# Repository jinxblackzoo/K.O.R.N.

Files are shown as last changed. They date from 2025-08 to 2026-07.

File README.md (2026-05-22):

# K.O.R.N.
**Katastrophal Organisierter Runder Nahrungsmittelspender**

K.O.R.N. ist ein robuster, Open-Source/Hardware, wasserdichter, mit einfachen Mitteln konstruierter und mäusesicherer Fütterungsautomat für Geflügel.

## Lizenz
Attribution-NonCommercial-ShareAlike 4.0 International

## 🎯 Projektübersicht

Aufgrund der enttäuschenden Erfahrung mit gekauften Fütterungsautomaten welche trotz der teils hohen Preise entweder nach drei Wochen defekt waren, oder ganze Mäusefamilien durchfütterten, musste eine Eigenkonstruktion her. Die Entscheidungsgrundlage für das gewählte System mit einer Förderschnecke in einem Rohr, basiert auf einer Recherche im Dubbel Ausgabe von 2001.

Es handelt sich um einen **Stetigförderer (Schnecke)**, der Schüttgut (Futter) aus einem Silo (KG-Rohr) in einen Auswurfschacht befördert. Das Gehäuse besteht aus überall erhältlichen, robusten und günstigen HT-, bzw KG-Rohren.

## Revision 1 wurde verworfen

## Revision 2 enthält die neuen CAD-Dateien und eine Steuerung mit ARDUINO Uno R3

Revision 2 wurde entwickelt als supersimple, autarke und stromsparende Version ohne Extra-Features.

## Revision 3 basiert auf den CAD Dateien von Rev.2 und einer Steuerung mit ARDUINO Uno R4 WiFi ✅ Fertig

Revision 3 wurde entwickelt als autarke Off-Grid Funktion. Ein WLAN mit Internetverbindung ist hier nicht vorgesehen.
Stattdessen kann KORN mitten im Feld ohne eigene Internetverbindung installiert werden. Der Arduino UNO R4 spannt einen eigenen WLAN Accesspoint auf. Mit diesem kann man sich mittels Smartphone verbinden.
Tipp: Alte Smartphones ohne Internet/Benutzerdaten einfach auf Werkseinstellungen zurücksetzen. Dann mit dem WLAN "KORN" verbinden und im Browser `192.168.4.1` öffnen. Voilà, fertig ist das eigene CCCC (ChickenCoopControlCenter) 🥳 😉

## Revision 3.5 basiert auf Rev.3 (Arduino UNO R4 WiFi) mit neuer WLAN-Logik ✅ Fertig

Revision 3.5 verwendet die gleiche Hardware und CAD wie Rev.3/Rev.4, ändert jedoch den WLAN-Betrieb grundlegend:
Statt eines eigenen Access Points verbindet sich KORN nun mit einem vorhandenen Heimnetz (WLAN-Router).

**Neue Features:**
- **DHCP-Hostname "KORN"**: Im Router als Gerät "KORN" sichtbar, direkt erreichbar unter `http://korn` (FritzBox, Speedport, OpenWRT)
- **Captive Portal**: Automatische Browser-Öffnung bei Einrichtungs-AP (`KORN-Setup`, PW: `Chaosfeeder`)
- **NTP-Zeitsteuerung**: Internetzeit statt DS1302 RTC (mit Sommer-/Winterzeit)
- **Buzzer-Jagdsignal**: Akustisches Signal "Zum Essen" (3/8-Takt) während der Fütterung
- **WPA2-Unterstützung** mit Passwort-Validierung (8-63 Zeichen)
- **Optionales Admin-Passwort**: Web-UI-Schutz vor unautorisierten Zugriffen im Heimnetz
- **Hardware-Recovery**: Bei vergessenem Passwort – Knopf (Pin 10↔11) zur Laufzeit 10s halten → EEPROM-Reset (Buzzer warnt ab 5s, Abbruch durch Loslassen möglich)

**24/7-Betriebssicherheit:**
- **Hardware-Watchdog (4s)**: Automatischer Reboot bei Code-Hängern
- **Stromausfall-Schutz**: EEPROM persistiert letzte Fütterung → keine Doppel-Fütterung nach Reboot
- **Robuster WLAN-Reconnect**: Bei vorhandenen Credentials kein automatischer Setup-AP-Modus
- **HTTP-Timeouts optimiert**: 500ms statt 1500ms → weniger Loop-Blockaden
- **XSS-Schutz**: HTML-Escaping & URL-Encoding für Admin-Passwort
- **NTP-Drift-Schutz**: Erkennt kleine Rückwärtssprünge bei NTP-Resync und verhindert dadurch ausgelöste Geister-Fütterungen (Mai 2026)

**Diagnose & Monitoring:**
- **Volles Datum + Uhrzeit** (`YYYY-MM-DD HH:MM:SS`) auf Web-UI und seriellem Monitor
- **Event-Log auf der Webseite** (`/log`): RAM-Ringpuffer mit den letzten 24 Scheduler-Ereignissen (Boot, NTP-Sync, Crossings, Trigger, Tageswechsel, Drift) – Fehlersuche ohne angeschlossenen Laptop

**Ablauf:** Beim ersten Start oder bei fehlendem WLAN öffnet der Arduino einen temporären Einrichtungs-AP. Nach Speichern der Zugangsdaten verbindet sich KORN automatisch mit dem Heimnetz.

📖 **Detaillierte Dokumentation:** [`KORN_Rev3.5/README_REV3.5.md`](./KORN_Rev3.5/README_REV3.5.md)

## Revision 4 basiert auf Rev.3/3.5 CAD mit neuem Controller: Raspberry Pi Pico W (Geplant)

Revision 4 übernimmt die überarbeiteten CAD-Dateien (Wendel 4.0, neuer Achsträger, Arduino-Träger als Pico-Träger).
Als Controller wird ein Raspberry Pi Pico W eingesetzt. Die Software wird in MicroPython neu geschrieben.
Ebenfalls geplant ist eine eigene Platine für eine sauberere Verkabelung und Befestigung.

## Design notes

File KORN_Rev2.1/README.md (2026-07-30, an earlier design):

# K.O.R.N.
**Katastrophal Organisierter Nahrungsmittel Spender**

K.O.R.N. wurde geplant als robuster, Open-Source/Hardware, wasserdichter, mit einfachen Mitteln konstruierter und mäusesicherer Fütterungsautomat für Geflügel.

Aufgrund der enttäuschenden Erfahrung mit gekauften Fütterungsautomaten, welche trotz teils hoher Preise entweder nach drei Wochen defekt waren oder ganze Mäusefamilien durchfütterten, musste eine Eigenkonstruktion her. Die Entscheidungsgrundlage für das gewählte System mit einer Förderschnecke in einem Rohr basiert auf einer Recherche im Dubbel, Ausgabe von 2001.

Es handelt sich um einen Stetigförderer (Schnecke), der Schüttgut (Futter) aus einem Silo (KG-Rohr) in einen Auswurfschacht befördert. Die Fütterungszeit und die Menge sind im Arduino-Code einstellbar. Das Gehäuse besteht aus überall erhältlichen, robusten und günstigen HT- bzw. KG-Rohren, die das Futter vor Mäusen, Insekten und Feuchtigkeit schützen sollen.

Die elektronischen Bauteile sind leicht verfügbar, standardisiert und günstig zu beschaffen. Alle Datenblätter und Schaltpläne sind online auffindbar.

Die Bauteile der Förderschnecke wurden mit FreeCAD (LGPL2+, CC-BY-3.0) entworfen. Die Förderschnecke wurde steckbar entworfen, sodass sie auch auf kleineren 3D-Druckern gedruckt werden kann.

## Funktionsweise Rev2

Der Arduino UNO R4 WiFi steuert über eine **DS3231 Echtzeituhr (RTC)** eine tägliche Fütterungszeit. Das Datum der letzten Fütterung wird im flash-emulierten EEPROM des R4 WiFi gespeichert und überlebt so Stromausfälle und Resets. Die Fütterung erfolgt innerhalb eines definierbaren Fensters um die Zielzeit herum; danach gibt es ein Nachholfenster. Anschließend schaltet ein Relais die Stromversorgung des Motortreibers ein, der NEMA-17-Stepper fördert das Futter für eine einstellbare Dauer und wird danach wieder stromlos geschaltet.

## Materialliste

**Gekauft:**
- 1x NEMA-17 Stepper Motor (z. B. 17HS15-1504S-X1)
- 1x Arduino UNO R4 WiFi
- 1x DM320T Motortreiber
- 1x Relais-Modul (z. B. HW-482)
- 1x DS3231 RTC-Modul
- Diverse KG-/HT-Rohre
- Diverse Kabel und 5-mm-Stecker für Arduino
- 12 V / 1,5 A Netzteil
- 4x Schrauben M3 für Stepper
- Kleber für PLA (z. B. Pattex Ultra Gel Sekundenkleber)

**Selbst gedruckt:**
- 3x 3D-Druck Förderschnecke/Wendel
- 1x 3D-Druck Achsträger
- 1x 3D-Druck Motorträger
- 1x 3D-Druck Zahnrad-Achse
- 1x 3D-Druck Achse-Achsträger

## Verdrahtung

**DS3231 RTC:**
- VCC → Arduino 3,3 V oder 5 V
- GND → Arduino GND
- SDA → Arduino A4 (SDA)
- SCL → Arduino A5 (SCL)
- SQW → nicht anschließen! (Pin 2 ist durch PUL belegt; bei Bedarf z. B. Pin 7 nutzen)

**Motortreiber:**
- PUL+ → Arduino Pin 2
- DIR+ → Arduino Pin 3
- ENA+ → Arduino Pin 5

**Relais:**
- Relais IN → Arduino Pin 8

**EEPROM-Reset:**
- Jumper/Kabel zwischen Pin 12 und Pin 13 → löscht das gespeicherte Fütterungsdatum
- Beim Start: sofort löschen
- Im laufenden Betrieb: Jumper mindestens 3 Sekunden halten
- Nach dem Löschen Jumper entfernen (ansonsten wird bei jedem Neustart gelöscht)

## Konfiguration im Code

Die wichtigsten Parameter in `main/KORN-Motorsteuerung_Rev2.1_R4WiFi/KORN-Motorsteuerung_Rev2.1_R4WiFi.ino`:

> **Hinweis:** Die hier gezeigten Werte sind **Beispielwerte**. Alle Parameter (Fütterungszeit, Fütterungsdauer/Menge, Timing) werden direkt im Code an die eigenen Gegebenheiten angepasst (z. B. Größe der Hühnerschar) und können von diesem Beispiel abweichen.

```cpp
// Fütterungszeit (24h-Format)
// ACHTUNG: Keine führende Null verwenden (z.B. 07, 09) - C++ wertet das als Oktalzahl!
const int FUETTERUNG_STUNDE_1 = 7;   // Fütterung: 07:01 Uhr
const int FUETTERUNG_MINUTE_1 = 1;

// Motorparameter
const int MOTOR_BESCHLEUNIGUNG = 2000; // Beschleunigung in Steps/s²
const int SCHRITTFREQUENZ = 1000;      // Steps pro Sekunde (fix)
const int FUETTERUNG_DAUER_SEK = 5;    // Fütterungsdauer in Sekunden (1–60 s)
const bool MOTOR_RECHTS = false;        // true = rechts (CW), false = links (CCW)

// Timing-Parameter
const int RELAIS_VERZOEGERUNG = 2000;  // ms zwischen Relais-Ein und Motor-Start
const int MOTOR_PAUSE = 5000;          // ms nach Motorlauf bevor Relais aus
const int LOOP_INTERVALL = 10;         // Sekunden zwischen zwei Loop-Durchläufen
const int ZEIT_AUSGABE_INTERVALL = 10; // Statusausgabe alle 10 Sekunden
const int FUETTERUNGS_FENSTER_MIN = 2; // Fütterungsfenster: Zielzeit bis +2 Minuten
const int NACHHOLFENSTER_MIN = 60;    // Nachholfenster: Zielzeit bis +60 Minuten

// Automatische Zeitsynchronisation
const bool ZEIT_EINSTELLEN = false;    // Nur true, wenn lostPower() oder explizit gewünscht
```

**Hinweis zur Zeit:** Die RTC-Zeit wird automatisch auf die Build-Zeit gesetzt, wenn die RTC ihre Versorgung verloren hat (`lostPower()`) oder `ZEIT_EINSTELLEN` auf `true` gesetzt wird. Nach dem ersten Flashen ist eine manuelle Synchronisation nur bei Bedarf nötig.

**Serieller Monitor:** 9600 Baud einstellen.

## Fehlerverhalten / Sicherheit

- **RTC nicht gefunden:** Wird die DS3231 beim Start nicht erkannt, wird alle 5 Sekunden ein neuer Verbindungsversuch unternommen. Sobald die RTC wieder erreichbar ist, startet das System normal weiter.
- **Ungültige RTC-Zeit:** Liefert die RTC unplausible Werte (z. B. durch eine I2C-Störung), wird der Durchlauf übersprungen. Das verhindert falsche Tagesresets und Doppelfütterungen.
- **Watchdog:** Aktuell deaktiviert, da er einen Reset-Loop verursacht hat. Soll später über einen Hardware-Timer sauber wieder integriert werden.

## Fütterungslogik in einfachen Worten

Der Arduino merkt sich im EEPROM das **Datum der letzten Fütterung** (Tag, Monat, Jahr). Das reicht, weil sich das Datum durch Stromausfälle und Resets nicht verliert.

### Ablauf

1. **Beim Start** liest er dieses Datum aus dem EEPROM.
2. **Alle 10 Sekunden** liest er die aktuelle Uhrzeit und prüft die Fütterungsfenster.
3. Er berechnet die **Zielzeit** aus den konfigurierten Stunden/Minuten:
   - **Fütterungsfenster:** von Zielzeit bis Zielzeit + 2 Minuten
   - **Nachholfenster:** von Zielzeit + 2 Minuten bis Zielzeit + 60 Minuten
4. Wenn die aktuelle Uhrzeit in einem dieser Fenster liegt **und** an diesem Tag noch nicht gefüttert wurde, startet die Fütterung.
5. **Direkt vor dem Motorstart** wird das aktuelle Datum ins EEPROM geschrieben. Damit vermeidet der Arduino Doppelfütterungen, wenn der Strom während des Fensters mehrfach aus- und wieder eingeschaltet wird.
6. Nach dem Füttern läuft der Arduino weiter. Bis zum nächsten Tag passiert nichts mehr, weil das gespeicherte Datum jetzt mit dem aktuellen Tag übereinstimmt.

### Tageswechsel

Ein extra Reset um Mitternacht ist nicht nötig. Sobald der aktuelle Tag sich ändert, ist das gespeicherte Fütterungsdatum automatisch kleiner. Dadurch ist die Fütterung am nächsten Tag wieder freigegeben.

### Verhalten bei Stromausfall

| Situation | Verhalten |
|---|---|
| Strom weg **vor** der Fütterungszeit | Nach dem Einschalten wartet der Arduino, bis das Fütterungsfenster erreicht ist, und füttert dann. |
| Strom weg **im Fütterungsfenster** | Nach dem Einschalten füttert er sofort, weil das Datum noch nicht gespeichert war. |
| Strom weg **im Nachholfenster** | Nach dem Einschalten füttert er sofort nach. |
| Strom weg **während des Fütterns** | Das Datum wurde bereits gespeichert. Beim Neustart füttert er nicht erneut. |
| Strom weg **nach dem Füttern** | Das Datum ist gespeichert, es passiert bis zum nächsten Tag nichts mehr. |
| Strom weg **länger als 60 Minuten** | Es wird nicht nachgeholt. Die nächste Fütterung findet am nächsten Tag statt. |

> **Kompromiss:** Weil das Datum vor dem Motorstart gespeichert wird, kann ein Stromausfall während des eigentlichen Füttervorgangs nicht erkannt werden. Dafür wird das Risiko einer Doppelfütterung im Fütterungsfenster komplett vermieden.

## Software / Bibliotheken

Für den Arduino werden folgende Bibliotheken benötigt:
- [AccelStepper](https://www.airspayce.com/mikem/arduino/AccelStepper/)
- [RTClib](https://github.com/adafruit/RTClib)
- [Wire](https://www.arduino.cc/en/reference/wire) (Standardbibliothek)
- EEPROM (Standardbibliothek für Arduino UNO R4 WiFi)

## Code-Verlauf

1. **Setup:** Initialisierung von RTC, I2C, Ausgängen und Auslesen des letzten Fütterungsdatums aus dem EEPROM. Serielle Ausgabe erfolgt mit 9600 Baud. Optional: Jumper Pin 12↔13 löscht das Fütterungsdatum.
2. **Hauptschleife (alle 10 Sekunden):**
   - Plausibilitätsprüfung der RTC-Zeit.
   - Alle 30 Sekunden: Ausgabe von aktueller Zeit, Temperatur, letzter Fütterung und Zeit bis zur nächsten Fütterung.
   - Prüfung, ob das heutige oder gestrige Fütterungsfenster aktiv ist und an diesem Tag noch nicht gefüttert wurde.
   - Das Fütterungsdatum wird **vor** dem Motorstart ins EEPROM geschrieben, um Doppelfütterungen zu vermeiden.
   - Fütterungsvorgang: Relais ein → Motor aktivieren → Futter fördern → Motor deaktivieren → Relais aus.

## Ausblick

- Austausch des Arduino Uno gegen ein WLAN-fähiges Gerät.
- Anbindung an einen Telegram-Bot für Statusmeldungen.
- Manuelle Bedienelemente mit Display für Fütterungszeit, Menge und manuelle Abgabe.
- Förderschnecke in stabilerem Material als PLA drucken.

## Lizenz

K.O.R.N. wird als Open-Source-Projekt unter der Creative Commons Attribution-NonCommercial-ShareAlike (CC BY-NC-SA) veröffentlicht.

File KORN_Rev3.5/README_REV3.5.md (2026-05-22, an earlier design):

# K.O.R.N.
**Katastrophal Organisierter Runder Nahrungsmittelspender**

K.O.R.N. ist ein robuster, Open-Source/Hardware, wasserdichter, mit einfachen Mitteln konstruierter und mäusesicherer Fütterungsautomat für Geflügel oder jede andere Art von Hausgetier 😉

## 🎯 Projektübersicht

Aufgrund der enttäuschenden Erfahrung mit gekauften Fütterungsautomaten welche trotz der teils hohen Preise entweder nach drei Wochen defekt waren, oder ganze Mäusefamilien durchfütterten, musste eine Eigenkonstruktion her. Die Entscheidungsgrundlage für das gewählte System mit einer Förderschnecke in einem Rohr, basiert auf einer Recherche in der Dubbel-Ausgabe von 2001.

Es handelt sich um einen **Stetigförderer (Schnecke)**, der Schüttgut (Futter) aus einem Silo (KG-Rohr) in einen Auswurfschacht befördert. Das Gehäuse besteht aus überall erhältlichen, robusten und günstigen HT- bzw. KG-Rohren.

Revision 3.5 basiert auf der bewährten Rev3-Hardware (Arduino UNO R4 WiFi) und bringt eine neue WLAN-Logik: Statt eines eigenen Access Points verbindet sich KORN mit einem vorhandenen Heimnetz. Die Zeitsteuerung erfolgt über NTP (Internetzeit) – die DS1302 RTC entfällt vollständig.

Beim ersten Start oder wenn kein WLAN erreichbar ist, öffnet der Arduino automatisch einen temporären Einrichtungs-AP (`KORN-Setup`, PW: `Chaosfeeder`). Damit kann man per Handy die WLAN-Zugangsdaten eingeben. Nach dem Speichern startet der Arduino neu und verbindet sich mit dem Heimnetz. Die IP-Adresse wird beim Start seriell ausgegeben.

## ⚡ Hardware-Komponenten

### Arduino Uno + Stepper-Treiber System
- **Arduino UNO R4 WiFi** (Mikrocontroller)
- ~~DS1302 RTC~~ – entfällt, Zeitsteuerung über NTP
- **NEMA Stepper Motor** Antrieb
- **DM320T Stepper-Motor Treiber** Motortreiber
- **Relais-Modul JQC3F oder ähnliches NO/COM/NC** (Stromversorgung Motor ein/aus)
- **Aktiver Buzzer** (Akustische Warnsignale)
- **Pushbutton momentarily** (Pin 10+11 Kurzschluss)

### 🔌 Verkabelung
```
Stepper-Treiber DM320T (Steuersignale):
├── PUL+    → Arduino Pin 2 (Schrittimpulse)
├── DIR+    → Arduino Pin 3 (Drehrichtung)
├── ENA+    → Arduino Pin 5 (Motor aktivieren)
└── OPTO    → Arduino 5V  (gemeinsamer Plus Optokoppler)

Stepper-Treiber DM320T (Leistung):
├── GND     → 12V Netzteil -
├── +Vdc    → Relais NO
├── A+      → NEMA Stepper Motor
├── A-      → NEMA Stepper Motor
├── B+      → NEMA Stepper Motor
└── B-      → NEMA Stepper Motor

Buzzer:
├── VCC     → Arduino 5V
├── GND     → Arduino GND
└── SIG     → Arduino Pin 6

Pushbutton:
└── Pin 10 ↔ Pin 11 (Kurzschluss = manuelle Fütterung)

Relais:
├── S       → Arduino Pin 8
├── +       → Arduino 5V
└── -       → Arduino GND

Relais Schaltkontakte:
├── NO      → DM320T +Vdc
├── COM     → 12V Netzteil + (Mittlerer Pin)
└── NC      → nicht belegt

```

#### Hinweise zur Verdrahtung
* **DS1302 entfällt in Rev3.5** – Pins 7, 9, 12 sind frei.
* **DM320T** (Common-Cathode):
  - PUL−, DIR−, ENA− an Arduino GND
  - OPTO an Arduino 5V (gemeinsamer Plus der Optokoppler)
* **Relais**: 
  - HW-482: Kann ACTIVE-HIGH oder ACTIVE-LOW sein (je nach Modul-Variante)
  - **Test:** LED am Modul leuchtet bei HIGH = ACTIVE-HIGH, bei LOW = ACTIVE-LOW
  - Im Code anpassbar: `RELAY_ACTIVE_HIGH` in `motor.ino` (Standard: `true`)
  - Relais trennt nur die Plusleitung: 12V+ → COM → NO → +Vdc des DM320T
* **Manueller Knopf** (Pin 10↔11): 
  - Pin 11 als permanentes LOW (OUTPUT)
  - Pin 10 als INPUT_PULLUP
  - **Fütterung**: Knopf 1–3 Sekunden drücken & loslassen
  - **Factory Reset**: Knopf 10 Sekunden halten (Buzzer warnt ab 5s)
  - **Lockout**: Während Fütterung + 2s danach wird der Knopf ignoriert
* **ENA-Logik**: ENA=HIGH aktiviert den Treiber; ENA=LOW deaktiviert

## 🚀 Software-Features

### ⏰ Intelligente Fütterungslogik
* **Automatischer Zeitplan**: Bis zu 2 Fütterungszeiten täglich
* **Sicherheitsabstand**: Mindestens 2 Minuten zwischen Fütterungen
* **Verzögerungsanzeige**: Bei zu häufigen Fütterungsversuchen wird die exakte Wartezeit angezeigt
* **Erweiterte Laufzeit**: 1–600 Sekunden (10 Minuten) für unterschiedliche Futtermengen
* **Live-Updates**: Webseite zeigt aktuelle Uhrzeit und letzte Fütterung in Echtzeit

### 💾 Konfigurationsspeicherung & Datensicherheit
* **EEPROM**: Konfiguration und WLAN-Zugangsdaten werden dauerhaft im EEPROM gespeichert
* **Automatisches Backup**: Bei jedem Speichervorgang wird EEPROM aktualisiert
* **Status-Anzeige**:
  - **CFG:EEPROM** = Aus EEPROM geladen (normal)
  - **CFG:DEF** = Standard-Werte (erster Start)
* **EEPROM-Lebensdauer**: ~100.000 Schreibzyklen (bei normaler Nutzung jahrelang haltbar)

### 📱 Benutzerfreundliche Bedienung

* **WLAN-Client-Modus**: KORN verbindet sich mit dem Heimnetz (Router)
* **Ersteinrichtungs-AP mit Captive Portal**: Bei erstem Start oder fehlendem WLAN öffnet sich `KORN-Setup` (PW: `Chaosfeeder`) → Browser öffnet sich **automatisch** mit der Einrichtungsseite (Captive Portal, wie bei Hotels/Cafés)
* **Hostname „KORN"**: Arduino meldet sich beim Router als **`KORN`** an (DHCP Option 12) – erscheint unter diesem Namen in der Router-Oberfläche. Bei vielen Routern (FritzBox, Speedport, OpenWRT) ist KORN direkt unter `http://korn` oder `http://korn.fritz.box` erreichbar.
* Einfache Handy-Webseite (mobilfreundlich):
  - Zwei Fütterungszeiten einstellen
  - Zweite Fütterungszeit deaktivieren
  - Motor-Laufzeit in Sekunden festlegen (1–600 Sekunden = bis zu 10 Minuten)
  - Countdown bis zur nächsten Fütterung mit Live-Uhr
  - Button "Jetzt füttern" mit 2-Minuten-Mindestabstand
  - Intelligente Verzögerungsanzeige: Zeigt exakte Uhrzeit bei Mindestabstand-Verzögerung
  - Letzte Fütterung wird live aktualisiert (Zeit + Quelle: Manuell/Web/Timer)
  - Warn-Button „Blockade lösen (Rechtslauf)“ mit Laufzeit-Eingabe (Standard 2 s; Begrenzung 1–60 s). Nur kurzfristig verwenden!
  - NTP-Status-Anzeige: Grün = synchronisiert, Rot = kein NTP-Sync
  - **Datum + Uhrzeit**: Vollständige Anzeige im Format `YYYY-MM-DD HH:MM:SS` (Web-UI + Serial Monitor)
  - **Diagnose-Log (`/log`)**: Button "📋 Event-Log anzeigen" auf der Startseite – zeigt die letzten 24 Scheduler-Ereignisse (BOOT, NTP sync, CFG saved, CROSS1/CROSS2, TRIG SCHED1/SCHED2, DAY rollover, NTP drift) mit vollem Zeitstempel. Ersetzt den seriellen Monitor für Fehlersuche unterwegs.
  - Robuste HTTP-Header: No-Cache, Connection: close, Sicherheits-Header
  - 303 Redirect nach Formularaktionen (verhindert doppeltes Absenden bei Reload)
  - Footer mit GitHub-Link und Build-Datum
* Manuelle Bedienung:
  - Knopf an Pin 10 ↔ 11 (1–3s drücken = Fütterung)
  - 10s halten = Factory Reset (Buzzer warnt ab 5s)
  - Sofortige Fütterung unabhängig vom Zeitplan
* Automatische Sommer-/Winterzeit (Europa/Berlin via NTP-Heuristik)
* NTP-Resync alle 60 Minuten
* Tages-Reset um Mitternacht
* Stepper-Reset nach jeder Bewegung

> Hinweis: WLAN-Client-Betrieb
> - KORN verbindet sich mit dem Heimnetz; die IP-Adresse wird beim Start seriell ausgegeben.
> - Webseite im Browser über die angezeigte IP öffnen (z.B. `http://192.168.1.42`).
> - Während der Motor läuft, bleibt die Seite im Lademodus – das ist normal. Sobald der Motor stoppt, lädt sie wieder.

#### Zugangsdaten Einrichtungs-AP
- Einrichtungs-AP SSID: `KORN-Setup`
- Einrichtungs-AP Passwort: `Chaosfeeder`
- Einrichtungsseite: `http://192.168.4.1/setup`

Wo ändern?
- Datei: `Script_KORN_REV3.5/main/wifi_client.ino`
- Konstanten am Dateianfang:

```cpp
static const char* SETUP_AP_SSID = "KORN-Setup";
static const char* SETUP_AP_PASS = "Chaosfeeder";
```

Hinweise:
- Heimnetz-WLAN-Zugangsdaten werden über die Einrichtungsseite gesetzt und im EEPROM gespeichert.
- **WPA2-PSK erforderlich**: Der UNO R4 WiFi unterstützt nur WPA2. WPA3-only oder WPA2/WPA3 mixed mode können Verbindungsprobleme verursachen. Im Router auf **WPA2 only** stellen (oder separates 2.4GHz-Gastnetz mit WPA2 einrichten).

#### 🔍 KORN im Heimnetz erreichen

KORN meldet sich beim Router mit dem Hostname **`KORN`** an. Je nach Router:

**Am einfachsten (FritzBox, Speedport, OpenWRT):**
- Browser öffnen → **`http://korn`** eingeben → fertig
- FritzBox alternativ: `http://korn.fritz.box`

**Falls das nicht klappt (UniFi, Vodafone, Billig-Router):**
- **Router-Oberfläche**: Verbundene Geräte → nach **„KORN"** suchen → IP notieren
- **Router-App**: Fritz!App, UniFi Network → DHCP-Liste → „KORN"
- **Serieller Monitor** (nur bei Entwicklung): Arduino IDE → 115200 Baud → IP wird beim Start ausgegeben

**Tipp für alle Nutzer**: Im Router eine **DHCP-Reservierung** für KORN einrichten → IP bleibt dauerhaft gleich → als Lesezeichen speichern.

#### 🔒 Verborgene SSIDs (Hidden Networks)
Funktioniert – einfach den exakten Netzwerknamen in das SSID-Feld der Einrichtungsseite eintippen (Groß-/Kleinschreibung beachten). Das Netzwerk muss nicht in einer Scan-Liste sichtbar sein.

### 🧰 Standardwerte
* Fütterungszeit 1: 07:01
* Fütterungszeit 2: 16:01 (aktiv)
* Standard-Laufzeit: 5 s (erweitert auf 1–600 s = bis zu 10 Minuten für große Hühnerscharen)
* Blockadelöser (UI-Default): 2 s (nicht persistent, nur Eingabewert in der Seite)
* Mindestabstand zwischen Fütterungen: 2 Minuten (Sicherheitsfeature)

## 💾 Persistenz

* Konfiguration und WLAN-Zugangsdaten werden im **EEPROM** gespeichert und überstehen Stromausfälle.
* Sind keine gültigen Daten im EEPROM, lädt das Gerät **Werkseinstellungen** (Defaults).
* Indikatoren in der seriellen Ausgabe: `NTP: OK/--`, `CFG: EEPROM/DEF`.

#### 🔄 Factory Reset (Werkseinstellungen wiederherstellen)
**Wichtig:** Ein normaler Sketch-Upload löscht **nichts** – WLAN-Zugangsdaten und Konfiguration bleiben im EEPROM erhalten!

Für einen vollständigen Reset gibt es zwei Möglichkeiten:

**Option A – Über die Webseite (einfach):**
- Auf der Hauptseite den Button **"🗑️ Auf Werkseinstellungen zurücksetzen"** unter dem NTP-Status klicken
- Arduino startet neu mit leerem EEPROM → Einrichtungs-AP öffnet sich automatisch

**Option B – Hardware-Recovery (ohne PC, bei vergessenem Admin-Passwort):**
- Den **manuellen Knopf (Pin 10 ↔ 11) gedrückt halten**
- Nach 5 Sekunden beginnt der Buzzer zu piepen (Vorwarnung)
- Knopf **weiter halten** bis insgesamt 10 Sekunden
- Bei 10s: Buzzer aus + 3 lange Bestätigungs-Piepser → EEPROM wurde gelöscht
- KORN startet automatisch neu im Einrichtungs-AP `KORN-Setup`
- **Abbruch möglich**: Knopf vor 10s wieder loslassen → nichts passiert

**Option C – Per Sketch (falls Hardware-Recovery nicht möglich):**
- Arduino IDE: **Datei → Beispiele → EEPROM → eeprom_clear** öffnen
- Auf den Arduino flashen, warten bis serieller Monitor "Done clearing EEPROM" anzeigt
- Dann wieder den originalen KORN-Sketch flashen

**Was bleibt erhalten (normaler Betrieb):**
- Stromlosigkeit, Reboots, WLAN-Verbindungsverluste → **EEPROM bleibt gespeichert**
- Sketch-Updates → **EEPROM bleibt gespeichert**

---

## 🖥️ Serieller Monitor

- Baudrate: **115200 Baud**
- Datenbits/Parität/Stoppbits: 8-N-1 (Standard)
- Zeilenende: No line ending (keine Eingaben erforderlich)
- Port: das ACM-Gerät des Boards (z. B. `/dev/ttyACM0`)

### Was zeigt der serielle Monitor?

Hauptsächlich für Entwickler und Fehlersuche. Er zeigt:

• **WLAN-Status**: Verbundenes Heimnetz (SSID) und IP-Adresse
• **Aktuelle Uhrzeit**: Datum und Uhrzeit der internen Uhr
• **Letzte Fütterung**: Wann zuletzt gefüttert wurde und wie lange der Motor lief
• **Nächste Fütterung**: Countdown bis zur nächsten automatischen Fütterung
• **NTP-Status**: Ob die Uhrzeit über NTP synchronisiert ist
• **Betriebszeit**: Wie lange das Gerät bereits läuft

**Beispiel einer Statuszeile:**
```
SSID:MeinHeimnetz IP:192.168.1.42 | TIME:2026-05-22 18:48:15 | Last:17:10(5000) | Next1:19:00(T-00:12) Next2:-- [off] | Steps:5000 | NTP:OK CFG:EEPROM | Up:00:32
```

**Bedeutung:**
- Verbunden mit WLAN "MeinHeimnetz", IP 192.168.1.42
- Aktuelles Datum + Zeit: 2026-05-22 18:48:15 (per NTP, inkl. Sommer-/Winterzeit)
- Letzte Fütterung: um 17:10 Uhr
- Nächste Fütterung: um 19:00 Uhr (in 12 Minuten)
- NTP: synchronisiert
- Gerät läuft seit 32 Minuten

---

## 🛡️ 24/7-Betriebssicherheit

KORN Rev3.5 ist für unbeaufsichtigten Dauerbetrieb ausgelegt. Folgende Mechanismen schützen vor Ausfällen:

### ⏱️ Watchdog
- **Hardware-Watchdog (4s Timeout)** auf UNO R4 aktiviert (`WDT.h`)
- Wenn der Code irgendwo hängt > 4s → automatischer Neustart
- Wird in `loop()` und während Motorlauf periodisch zurückgesetzt
- **Aktivierung erst nach WLAN-/NTP-Init**, weil `WiFi.begin()` intern länger als 4s blockieren kann (Kommunikation mit ESP32-S3-WiFi-Coprozessor). Während Boot ist der Nutzer eh anwesend.

### 🔌 Stromausfall-Verhalten
- **EEPROM persistiert**: WLAN-Daten, Konfiguration, Admin-Passwort, **letzte Fütterung & Tagesmarker**
- **Schutz vor Doppel-Fütterung**: Nach Stromausfall weiß KORN noch, ob heute schon gefüttert wurde
- **Stepper sicher**: Bei Stromverlust stoppt Motor sofort, Position wird beim Boot auf 0 gesetzt
- **Relais fällt ab**: Stepper-Treiber erhält keine 12V mehr, kein wilder Motorlauf

### 🌐 Internet-Ausfall
- **NTP-Resync alle 60min**, falls Internet zurückkommt
- **Bei kurzzeitigem Ausfall (< 24h)**: Zeit läuft per `millis()` weiter, geplante Fütterungen funktionieren
- **WLAN-Reconnect alle 30s**: Bei vorhandenen Credentials wird **kein Setup-AP** automatisch geöffnet
- **Bei langen Ausfällen**: Manuelle Fütterung per Hardware-Taster möglich (unabhängig von Internet/WLAN)

### 🔄 Was passiert bei...
| Szenario | Verhalten |
|---|---|
| **Stromausfall < 1 Min** | Reboot → EEPROM-Daten geladen → keine Doppel-Fütterung |
| **Stromausfall > 5 Min** | Reboot, NTP-Sync → evtl. verpasste Fütterung wird **NICHT** nachgeholt |
| **WLAN-Ausfall** | Geplante Fütterungen laufen weiter (Zeit per `millis()` Drift) |
| **Internet-Ausfall (DSL)** | Wie WLAN-Ausfall: NTP-Resync schlägt fehl, Zeit driftet |
| **Code-Hänger** | Watchdog löst Reboot nach 4s aus |
| **Router-Reboot** | Reconnect alle 30s, max. 3 Versuche im Vordergrund |

---

## 🐔 Häufige Fragen für Hühnerfreunde

> Einfache Antworten für alle, die kein IT-Studium haben.

### ❓ Was passiert, wenn der Strom kurz weg war?
**Nichts Schlimmes.** KORN startet neu und läuft normal weiter. Das Gerät merkt sich im internen Speicher, ob heute schon gefüttert wurde – **deine Hühner bekommen nicht zweimal Futter**. Die Uhrzeit wird automatisch aus dem Internet geholt (NTP), sobald das WLAN wieder da ist.

### ❓ Was ist, wenn ich das Admin-Passwort vergesse?
**Kein Problem – einfach den manuellen Knopf 10 Sekunden gedrückt halten:**
1. Knopf (Pin 10↔11) drücken und **halten**
2. Nach 5 Sekunden beginnt der Buzzer zu piepen (Vorwarnung)
3. Knopf weiter halten, bei 10 Sekunden hört das Piepen auf, dann kommen 3 lange Bestätigungs-Piepser
4. KORN startet automatisch neu im Einrichtungs-Modus (`KORN-Setup`, Passwort `Chaosfeeder`)

**Reset abbrechen:** Den Knopf während des Piepens (5-10s) wieder loslassen.

### ❓ Fallen meine Hühner vom Futter, wenn das Internet ausfällt?
**Für ein paar Stunden: nein.** KORN hat die Uhrzeit im Speicher und füttert weiter nach Plan. Bei langen Ausfällen (mehrere Tage) könnte die Zeit ein paar Minuten falsch laufen – aber gefüttert wird trotzdem. Notfalls kannst du immer den **manuellen Taster** drücken (funktioniert auch ohne Internet und WLAN).

### ❓ Der Router wurde neu gestartet – was nun?
**KORN verbindet sich automatisch wieder.** Alle 30 Sekunden wird geprüft, ob das Heimnetz zurück ist. Du musst nichts tun.

### ❓ Geht das Gerät kaputt, wenn es 24/7 läuft?
**Nein, es ist dafür gemacht.** Ein Hardware-Watchdog startet das Gerät automatisch neu, falls die Software mal hängen sollte (selten). Der Speicher ist robust genug für **über 100 Jahre** Dauerbetrieb mit zwei Fütterungen pro Tag.

### ❓ Kann meine Nachbarin an meine Hühnerfütterung?
**Nur wenn sie dein WLAN hat.** KORN ist **nicht aus dem Internet** erreichbar, nur aus deinem Heimnetz. Zusätzlich kannst du ein Admin-Passwort setzen, dann kommt auch niemand ohne dieses Passwort rein – selbst wenn jemand im WLAN ist.

### ❓ Muss KORN immer mit dem Computer verbunden sein?
**Nein.** Der USB-Anschluss ist nur für das erste Aufspielen der Software nötig. Danach braucht KORN nur einen Stromanschluss und WLAN.

### ❓ Wo sehe ich, ob KORN gerade läuft?
Rufe im Browser `http://korn` auf (oder die IP-Adresse). Dort siehst du:
- Aktuelle Uhrzeit
- Wann zuletzt gefüttert wurde
- Wann die nächste Fütterung kommt
- Status des Geräts

---

## 🔑 Admin-Passwort (optional)

Beim Einrichten kann ein **Admin-Passwort** (4-32 Zeichen) vergeben werden, um die Web-UI zu schützen.

**Verhalten:**
- **Leer gelassen** → KORN ist im Heimnetz frei zugänglich (jeder mit IP-Adresse)
- **Gesetzt** → Beim ersten Zugriff erscheint eine Login-Seite, das Passwort wird anschließend in der URL und in Formularen weitergereicht

**Geändert wird das Passwort durch:**
1. Factory Reset (Web-UI Button **oder** Hardware-Recovery)
2. Neue Einrichtung mit anderem Admin-Passwort

**Vergessen? → Hardware-Recovery:**
- Manuellen Knopf (Pin 10↔11) **10 Sekunden** gedrückt halten
- Buzzer piept ab 5s als Vorwarnung
- Bei 10s: 3 lange Piepser → EEPROM gelöscht, KORN startet automatisch im Setup-AP

**Sicherheitshinweise:**
- Passwort wird **unverschlüsselt** über HTTP übertragen → nur im vertrauenswürdigen Heimnetz nutzen
- Passwort wird im EEPROM **im Klartext** gespeichert
- Schützt nicht vor Netzwerk-Sniffing, aber vor versehentlichen Klicks und unautorisierten Nutzern im LAN

---

## 🏗️ Hardware-Design

Die Bauteile der Förderschnecke wurden mittels FreeCAD (LGPL2+, CC-BY-3.0) entworfen. Die Förderschnecke wurde steckbar entworfen, somit ist es möglich, die Schnecke auch auf kleineren 3D-Druckern zu drucken.

**Konstruktionsprinzipien:**
- **Robuste KG-/HT-Rohre** als Gehäuse
- **Mäuse- und insektensicher**
- **Wasserdicht und witterungsbeständig**
- **Einfach zu reinigende Komponenten**
- **Standardisierte, verfügbare Bauteile**

---

## 🔧 Wartung & Troubleshooting

### Häufige Probleme und Lösungen

#### Webseite lädt nicht
* **IP unbekannt**: Serielle Ausgabe lesen (115200 Baud) – IP wird beim Start ausgegeben
* **Seite nicht erreichbar**: Sicherstellen, dass Handy/PC im gleichen Heimnetz ist

#### WLAN-Probleme
* **Arduino verbindet sich nicht / Timeout**: 
  - Einrichtungs-AP `KORN-Setup` öffnet sich automatisch → `http://192.168.4.1/setup` aufrufen
  - **WPA2-PSK prüfen**: Router muss WPA2-only unterstützen (WPA3 oder Mixed-Mode verursachen Timeouts)
  - SSID und Passwort exakt prüfen (Groß-/Kleinschreibung, keine Leerzeichen)
* **Kein NTP-Sync**: Internetverbindung des Routers prüfen

#### Fütterung funktioniert nicht
* **"Jetzt füttern" reagiert nicht**: 
  - 2 Minuten seit letzter Fütterung warten
  - Webseite zeigt dann exakte Wartezeit an
* **Motor dreht nicht**: 
  - 12V-Netzteil angeschlossen und eingeschaltet?
  - Alle Kabel fest verbunden?
  - Grünes Lämpchen am Arduino leuchtet?

#### NTP-Probleme
* **Roter NTP-Button**: Router hat keine Internetverbindung, oder NTP-Server nicht erreichbar
* **Einstellungen gehen verloren**: Nur bei EEPROM-Fehler (sehr selten) – siehe [Factory Reset](#-factory-reset-werkseinstellungen-wiederherstellen)

### Notfall-Fütterung (Hardware-Knopf)
Falls die Webseite nicht funktioniert: Knopf an Pin 10↔11 **1–3 Sekunden** drücken und loslassen → Sofortige Fütterung wird ausgelöst (umgeht 2-Minuten-Regel).

---

## 🔒 Sicherheit & Firewall

**KORN Rev3.5 ist ein IoT-Gerät ohne eingebaute Sicherheitsfeatures.** Diese Übersicht hilft bei der eigenen Risikobewertung. Jeder soll selbst entscheiden, ob und wie das Gerät eingesetzt wird.

### 🔴 Bekannte Risiken (kritisch)

| # | Risiko | Beschreibung | Warum vertretbar / nicht behoben |
|---|---|---|---|
| 1 | **HTTP statt HTTPS** | Webseite läuft auf Port 80 unverschlüsselt – Daten im LAN im Klartext sichtbar | Der Arduino UNO R4 WiFi unterstützt kein TLS als Server (nur als Client). HTTPS wäre technisch nicht umsetzbar ohne kompletten Hardware-Wechsel. Das einzige sensible ist das WLAN-Passwort bei der Ersteinrichtung – danach werden nur unkritische Fütterungsdaten übertragen. |
| 2 | **Optional: Login-Authentifizierung** | Web-UI kann durch ein Admin-Passwort geschützt werden (bei Einrichtung optional vergeben). Ohne Passwort hat jeder im Netzwerk vollen Zugriff. | Bei Einrichtung kann ein Admin-Passwort (4-32 Zeichen) gesetzt werden. Falls vergessen: Hardware-Recovery (Knopf Pin 10↔11 zur Laufzeit 10s halten) löscht das EEPROM. Ohne Admin-Passwort: Im privaten Heimnetz mit VLAN-Trennung tolerierbar. |
| 3 | **WLAN-Passwort im EEPROM (Klartext)** | Wer physischen Zugriff auf den Arduino hat, kann das WLAN-Passwort auslesen | Erfordert physischen Zugriff auf das Gerät + Arduino IDE + Spezialkenntnisse. Wer physischen Zugriff zum Hühnerstall hat, könnte das WLAN-Gerät ohnehin einfach mitnehmen. Arduino in abgeschlossenem Gehäuse minimiert dieses Risiko. |

### 🟡 Bekannte Risiken (mittel)

| # | Risiko | Beschreibung | Warum vertretbar / nicht behoben |
|---|---|---|---|
| 4 | **Kein Rate-Limit / DoS-Schutz** | Bei vielen Anfragen kann der Webserver überlastet werden | KORN ist nur im lokalen Netz erreichbar, nicht aus dem Internet. Ein gezielter DoS-Angriff aus dem eigenen Heimnetz ist kein realistisches Szenario. Worst Case: Webserver temporär nicht erreichbar, Fütterungslogik läuft weiter. **Watchdog (4s)** rettet bei Hängern. |
| 5 | **Einrichtungs-AP ohne Session-Schutz** | Im Setup-AP kann jeder (mit Passwort) WLAN-Daten ändern | Der Setup-AP ist mit WPA2 und Passwort (`Chaosfeeder`) gesichert. Nur wer das Passwort kennt, kommt rein. Setup-AP ist nur aktiv wenn kein WLAN verbunden – also nur kurzzeitig bei Ersteinrichtung oder nach Factory Reset. |
| 6 | **CSRF (Cross-Site Request Forgery)** | Bösartige Webseiten könnten Fütterung/Reset auslösen | Erfordert dass Nutzer gleichzeitig eine bösartige Webseite und die KORN-Seite offen hat, und ein Angreifer die interne KORN-IP kennt. Sehr unwahrscheinliches Szenario für ein Heimgerät. Worst Case: ungewollte Fütterung oder Reset. |
| 7 | **DNS-Server im Setup-Modus** | Captive Portal DNS-Server ist UDP-offen | DNS-Server läuft **ausschließlich** im Einrichtungs-AP-Modus und antwortet nur auf Anfragen im 192.168.4.x-Netz. Sobald KORN mit dem Heimnetz verbunden ist, wird der DNS-Server automatisch gestoppt. |

### 🟢 Bekannte Risiken (niedrig)

| # | Risiko | Beschreibung | Warum vertretbar / nicht behoben |
|---|---|---|---|
| 8 | **NTP-Outbound-Verkehr** | Arduino kontaktiert `pool.ntp.org` (UDP 123) | Standardverhalten aller NTP-Clients weltweit. Kein Angriffsvektor – es werden keine persönlichen Daten übertragen, nur ein Zeitstempel angefragt. Firewall-Regel erlaubt nur diesen einen Outbound-Port. |
| 9 | **Einrichtungs-AP öffnet sich automatisch** | Bei WLAN-Verlust wird der Setup-AP geöffnet | AP ist WPA2-gesichert mit Passwort. Öffnet sich nur wenn KORN kein Heimnetz erreicht (z.B. Router-Neustart). Wer das Setup-Passwort nicht kennt, kann nichts tun. |
| 10 | **Factory Reset ohne Passwort** | Jeder im Netz kann den Reset-Button drücken | Reset löscht nur EEPROM (WLAN-Zugangsdaten + Konfiguration) – keine persönlichen Daten, keine Dateien. Worst Case: KORN muss neu eingerichtet werden. Durch VLAN-Trennung hat niemand außer dem Admin Netzwerkzugriff auf das Gerät. |

### 🛡️ Firewall-Empfehlungen

- **VLAN-Trennung**: KORN in separates IoT-VLAN ohne Zugriff auf andere Netzwerkgeräte
- **Firewall-Regeln**: Nur NTP (UDP 123) erlauben, restlicher Internet-Verkehr blockieren
- **Port-Isolation**: LAN-Port auf IoT-VLAN taggen, falls per Kabel verbunden
- **Zugriffsbeschränkung**: HTTP-Port 80 nur für bestimmte Admin-IPs freigeben
- **WLAN-Settings**: „Client Isolation" im WLAN aktivieren (schützt andere Geräte)
- **Physischer Schutz**: Arduino in abgeschlossenem Gehäuse (schützt EEPROM-Zugriff)

### 📊 Empfehlung für private Nutzung
Für ein privates Setup (Hühnerstall, UniFi-Firewall mit VLAN-Trennung) ist das **Risiko vertretbar**:
- KORN nicht im gleichen VLAN wie sensible Geräte (NAS, Arbeits-PC)
- Firewall-Regeln begrenzen KORN auf das Minimum (NTP)
- Keine Weiterleitung von Ports nach außen (kein Internet-Zugriff auf KORN)

### ⚠️ Nicht empfohlen
- **Einsatz in fremden Netzen** (z.B. öffentliches WLAN)
- **Port-Weiterleitung aus dem Internet** auf KORN
- **Gemeinsames VLAN** mit sensiblen Geräten
- **Nutzung ohne Firewall-Konfiguration**

---

## ⚡ Stromverbrauch & Solarbetrieb

Für den Betrieb mit Solarstrom sind folgende Verbrauchswerte relevant. Hinweis: Rev3.5 benötigt eine Internetverbindung für NTP – ein WLAN-Router mit Internetzugang muss erreichbar sein:

### Gemessene Stromaufnahme bei 12V
- **Standby** (Motor aus, Relais aus, Arduino an): **0,093 A** (1,116 W)
- **Aktiv ohne Last** (Motor läuft, DM320T aktiv, ohne Futter): **0,86 A** (10,32 W)
- **Aktiv mit Last** (Motor läuft, DM320T aktiv, mit Futter): **1,3 A** (15,6 W)

### DM320T Konfiguration (aktuell)
Die Messwerte basieren auf folgender DIP-Schalter-Einstellung der Variante A:
- SW1=ON, SW2=ON, SW3=OFF, SW4=ON, SW5=ON, SW6=ON
- Entspricht: 1,3A Peak (0,92A RMS), Microstep 2

### Dimensionierung für Solarbetrieb

**Täglicher Energiebedarf (Beispielrechnung bei 3 Fütterungen à 10s MIT Futter):**
- Standby: 23,992h × 0,093A = 2,231 Ah/Tag (26,8 Wh/Tag)
- Fütterungen: 3× 10s × 1,3A = 0,011 Ah/Tag (0,13 Wh/Tag)
- **Gesamt: ~2,24 Ah/Tag (26,9 Wh/Tag)**

**Hinweis:** Standby-Verbrauch dominiert (>99%)! Selbst mit Futterlast spielt die Fütterungszeit kaum eine Rolle.

**Empfohlene Solaranlage:**
- Solarpanel: 20-30W (je nach Standort/Jahreszeit)
- Akku: 12V/7-12Ah (84-144 Wh Kapazität)
- Laderegler: 12V PWM/MPPT für entsprechende Panel-Leistung

**Beispiel-Konfiguration (getestet):**
- Solarpanel: 130W (deutlich überdimensioniert → sehr zuverlässig)
- Akku: 12V/12Ah Sealed Lead Acid (144 Wh nominal, ~72 Wh nutzbar)
- Laderegler: entsprechend 130W Panel dimensioniert

### Batterielaufzeit ohne Solar-Nachladung

**12V 12Ah Blei-Akku (SLA/AGM):**
- Nutzbare Kapazität: ~50% (um Lebensdauer zu erhalten) = 6 Ah
- Bei 3 Fütterungen/Tag (à 10s): **2,7 Tage** (≈ 65 Stunden)
- Bei längeren Fütterungen (3× 60s): **2,6 Tage** (≈ 62 Stunden)

**Wichtig:** Die Fütterungsdauer hat kaum Einfluss auf die Gesamtlaufzeit, da der Standby-Verbrauch dominiert (>99% der Energie).

**Hinweise:**
- Blei-Akkus: Nicht unter 50% Entladung betreiben (verkürzt Lebensdauer drastisch)
- Wintermonate: Größeres Panel oder zusätzliche Akkukapazität einplanen
- Sicherheitsreserve: Mind. 20% Buffer einrechnen
- Alternative: LiFePO4-Akkus bieten ~80% nutzbare Kapazität (≈4 Tage Laufzeit), sind aber teurer

---

## 🛠️ Entwicklung

Der Code wurde mit Hilfe von **künstlicher Intelligenz** entworfen, optimiert und systematisch verbessert. Das Projekt folgt **Open-Source-Prinzipien** und ist vollständig dokumentiert.

### 🗂️ Projektstruktur
```
KORN_Rev3.5/
├── Script_KORN_REV3.5/
│   └── main/
│       ├── main.ino          (Setup/Loop, NTP-Logik)
│       ├── wifi_client.ino   (WLAN-Client + Einrichtungs-AP)
│       ├── homepage.ino      (Webserver & Routen)
│       └── motor.ino         (Stepper, Relais, Buzzer)
├── cad/
├── pics_video_additional-info/
└── README_REV3.5.md
```

### ⚙️ DM320T DIP‑Schalter (Strom/Microstep)

Siehe `pics_video_additional-info/DM320T_user_manual.txt` (Abschnitt 7.1/7.2). Standstill-Current wird nach ~0,4 s automatisch auf 50% reduziert.

Varianten (konservativ → kräftiger), jeweils mit Microstep 2 für robustes Drehmoment bei Anlauf:

- __Variante A (sehr netzteilschonend, verbreitet)__
  - Dynamischer Strom: 1.3A Peak (0.92A RMS)
    - SW1=ON, SW2=ON, SW3=OFF
  - Microstep 2 (400 Steps/Rev):
    - SW4=ON, SW5=ON, SW6=ON
  - **Gemessener Verbrauch bei 12V:** 0,7A aktiv, 0,104A Standby
  - **Ideal für Solarbetrieb:** Minimaler Stromverbrauch, ~30 Wh/Tag

- __Variante B (konservativ, guter TQ)__
  - Dynamischer Strom: 1.6A Peak (1.13A RMS)
    - SW1=OFF, SW2=ON, SW3=OFF
  - Microstep 2 (400 Steps/Rev):
    - SW4=ON, SW5=ON, SW6=ON
  - **Gemessener Verbrauch bei 12V:** 0,920A aktiv, 0,105A Standby
  - **Solarbetrieb:** Höherer Verbrauch, ~37 Wh/Tag (23% mehr als Variante A)

- __Variante C (mehr TQ, prüfe Netzteil/Temperatur)__
  - Dynamischer Strom: 1.9A Peak (1.34A RMS)
    - SW1=ON, SW2=OFF, SW3=OFF
  - Microstep 2 (400 Steps/Rev):
    - SW4=ON, SW5=ON, SW6=ON
  - **Gemessener Verbrauch bei 12V:** 1,125A aktiv, 0,105A Standby
  - **Solarbetrieb:** Höchster Verbrauch, ~43 Wh/Tag (43% mehr als Variante A)

Hinweise:
- DM320T max. 2.2A Peak – nicht empfohlen bei 2A-Netzteilgrenze.
- Microstepping glättet Lauf, „per-Step“-Moment sinkt. Für hohe Durchsetzung unter Last sind 2 oder 4 Microsteps sinnvoll.
- Falls Motor nur „hält“: In `motor.ino` ggf. `ENABLE_ACTIVE_HIGH=false` und/oder `INVERT_STEP=true` setzen; gemeinsame Masse prüfen.

__Wann welche Variante?__
- **Variante A (1.3A Peak)**: Kleines/empfindliches Netzteil (≤2A), Dauerbetrieb/hohe Einschaltdauer, geringe bis mittlere Last. Fokus auf kühlen, zuverlässigen Betrieb.
- **Variante B (1.6A Peak)**: Standardempfehlung für K.O.R.N. mit 2A-Netzteil. Mittlere Last, kurze Laufzeiten (Fütterungszyklen), gutes Drehmoment bei moderater Erwärmung.
- **Variante C (1.9A Peak)**: Höhere Last/Anlaufmomente (z. B. gegen Futterbrücken) bei kurzen Einsätzen, gute Belüftung. Netzteil muss stabil ≥2A liefern. Nicht für langen Dauerbetrieb.

Tipps:
- Steigen Schritte aus → eine Stromstufe höher. Wird Treiber/Motor zu warm → eine Stufe runter.
- Bei rauem Lauf/Resonanzen Microstep auf 4 (SW4=OFF, SW5=ON, SW6=ON) testen.

### 🔌 DM320T Verkabelung (OPTO/PUL/DIR/ENA)

Der DM320T hat einzelne Logikeingänge `PUL`, `DIR`, `ENA` und eine gemeinsame Versorgungs‑Klemme `OPTO` (+5V für die Optokoppler). Empfehlung: „Common‑Anode“.

Verdrahtung (entspricht den Pins im Sketch `motor.ino`):

```
DM320T OPTO  → Arduino 5V  (aufteilen per Y‑Kabel/Breadboard; alternativ 5V‑Buck vom 12V‑Netzteil)
DM320T PUL   → Arduino D2
DM320T DIR   → Arduino D3
DM320T ENA   → Arduino D5   (zum Testen kann ENA unbeschaltet bleiben; Treiber ist i.d.R. enabled)

DM320T +Vdc  → Motornetzteil + (z. B. 12–24V)
DM320T GND   → Motornetzteil −
Arduino GND  ↔ DM320T GND (sternförmig verbinden; gemeinsame Masse als Referenz)

DM320T A+, A−, B+, B− → Motorphasen gemäß Motordatenblatt
```

Hinweise:
- `OPTO` ist der gemeinsame Plus für die Optokoppler‑LEDs. Die Arduino‑Pins „sinken“ Strom über `PUL/DIR/ENA` nach GND.
- VIN am Arduino ist ungeeignet für `OPTO`. Wenn 5V‑Pin belegt ist: 5V aufsplitten oder kleinen 5V‑Step‑Down (Buck) vom 12V‑Zweig nutzen und dessen GND mit Arduino‑GND verbinden.
- Signalführung kurz, sauber, möglichst verdrillt (z. B. PUL↔GND, DIR↔GND, ENA↔GND).

Passende Software‑Einstellungen (bereits im Code vorgesehen):
- In `Script_KORN_REV3.5/main/motor.ino` bei dieser Verdrahtung typischerweise:
  - `ENABLE_ACTIVE_HIGH = false`
  - `INVERT_STEP = true`
  - `INVERT_DIR` je nach Drehrichtung (falls invertiert → `true`)

### 📦 Arduino IDE: Benötigte Pakete & Bibliotheken

* __Board-Paket (Boards Manager)__
  - Arduino UNO R4 Boards (Renesas RA) – Board: „Arduino UNO R4 WiFi“ auswählen

* __Bibliotheken (Library Manager)__
  - AccelStepper (Autor: Mike McCauley / AirSpayce)
    - Stepper-Ansteuerung für den DM320T (`#include <AccelStepper.h>`)
  - WiFiS3 (vorinstalliert)
    - WLAN-Client und Webserver (`#include <WiFiS3.h>`)
  - WiFiUDP (vorinstalliert)
    - NTP-Kommunikation und DNS-Server für Captive Portal (`#include <WiFiUdp.h>`)
  - EEPROM (vorinstalliert)
    - Konfiguration und WLAN-Zugangsdaten speichern
  - ~~Rtc by Makuna~~ – entfällt (DS1302 nicht mehr verwendet)

Hinweise:
- Installation jeweils über „Werkzeuge → Bibliotheken verwalten…“, nach den oben genannten Namen suchen.
- Nach Installation Board „Arduino UNO R4 WiFi“ wählen und den richtigen COM/TTY-Port einstellen.
- Falls AccelStepper nicht gelistet ist: ZIP installieren über „Sketch → Include Library → Add .ZIP Library…“
  - ZIP: https://github.com/airspayce/AccelStepper/archive/refs/heads/master.zip

---

## 🐛 Bug-Historie / Bekannte Probleme

### Behoben: NTP-Drift verursacht Geister-Auslösung beider Termine kurz nach Mitternacht (Mai 2026)

**Symptom:** Termine 1 und 2 lösten gelegentlich nicht zur konfigurierten Uhrzeit aus. Stattdessen wurden beide Termine in der Nacht (typisch zwischen 00:56 und 01:56) hintereinander unbeabsichtigt ausgelöst, und die echten Auslösezeiten (z. B. 09:00 und 17:58) am selben Tag übersprungen.

**Ursache:** Der Quarz des UNO R4 läuft minimal schneller als die echte Zeit (Crystal-Drift). Innerhalb einer Stunde überholt die `millis()`-basierte Uhrzeitberechnung den realen NTP-Zeitstrom um ~1 s. Beim stündlichen NTP-Sync wird die Zeit um genau diese 1 s **rückwärts** korrigiert.

Die Crossing-Erkennung im Scheduler benutzte einen Wrap-Around-Branch (für Mitternacht), der **immer** griff, wenn die letzte abgespeicherte Sekunde größer war als die aktuelle:

```cpp
auto crossed = [](int lastS, int nowS, int tS) {
  if (lastS <= nowS) {
    return (tS > lastS) && (tS <= nowS);
  } else {
    return (tS > lastS) || (tS <= nowS);  // Wrap-Branch
  }
};
```

Bei einer Drift-Korrektur von z. B. `lastS=6976` auf `nowS=6975` lief der Wrap-Branch los und meldete **alle** Zielzeiten zwischen 6975 und 6976 + Tagesgrenze als überschritten – inklusive 09:00, 17:58, etc.

Folge: Beide Termine wurden als pending markiert und sofort gefüttert, dann am echten Termin durch `fedToday=1` blockiert.

**Heisenbug-Charakter:** Mit angeschlossenem Serial-Monitor war das Verhalten nicht reproduzierbar, weil zusätzliche `Serial.print`-Aufrufe das Loop-Timing minimal verschoben und damit auch den Drift gegen die NTP-Sync-Sekunde.

**Fix (`Script_KORN_REV3.5/main/main.ino`):** Vor der Crossing-Prüfung wird ein Rückwärtssprung von weniger als 12 h als Drift-Korrektur erkannt und `lastNowSec` auf `nowSec` gezogen. Echte Mitternacht-Wraps (Differenz > 12 h) bleiben unberührt.

**Diagnose:** Über die neue Webseite `/log` (Button auf der Startseite) lassen sich die letzten 24 Scheduler-Ereignisse einsehen, ohne Serial-Monitor: `BOOT`, `DAY rollover`, `CFG saved`, `CROSS1`/`CROSS2`, `TRIG SCHED1`/`TRIG SCHED2`, `NTP sync ok`, `NTP drift: skip crossing`.

---

**Status:** In Entwicklung | **Version:** Rev3.5 (2026) | **Lizenz:** Open-Source CAD-Hardware/Software

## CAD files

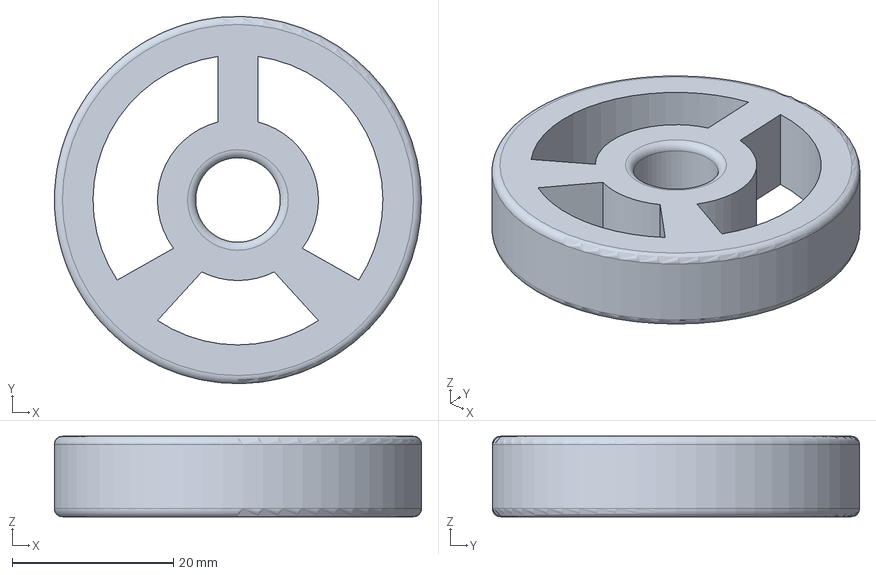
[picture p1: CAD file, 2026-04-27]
KORN_Rev4/cad/DN50_Achsträger_Rev4.FCStd
45.6 x 45.6 x 10.0 mm

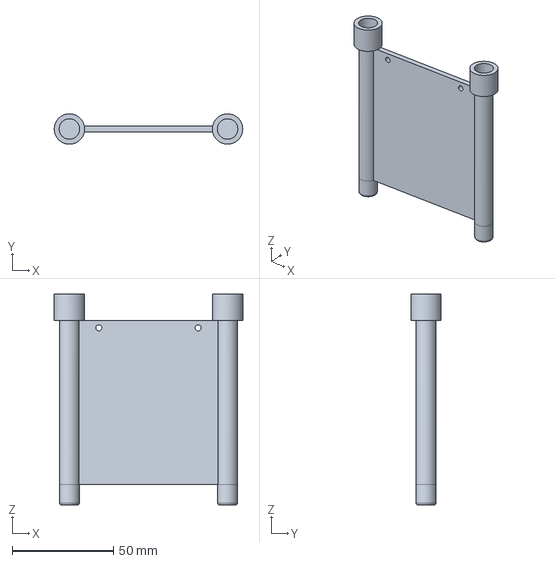
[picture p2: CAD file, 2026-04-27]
KORN_Rev4/cad/Arduino_Traeger.FCStd
92.9 x 15.0 x 104.0 mm

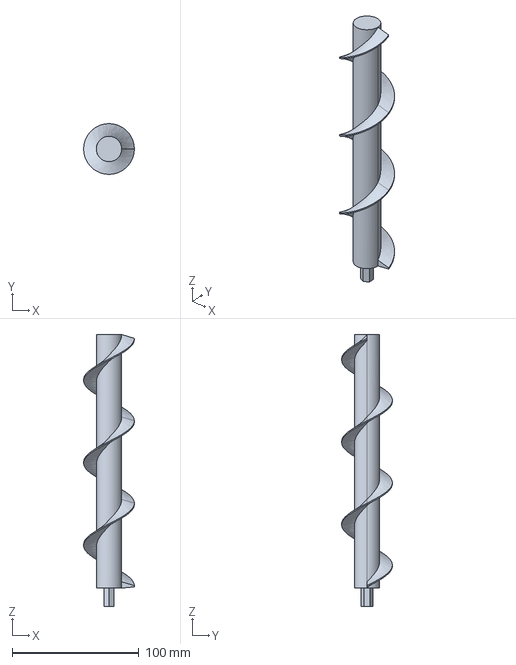
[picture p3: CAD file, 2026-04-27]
KORN_Rev4/cad/Wendel_4.0_steckbar_D-41_DN50.FCStd
40.0 x 40.0 x 214.5 mm

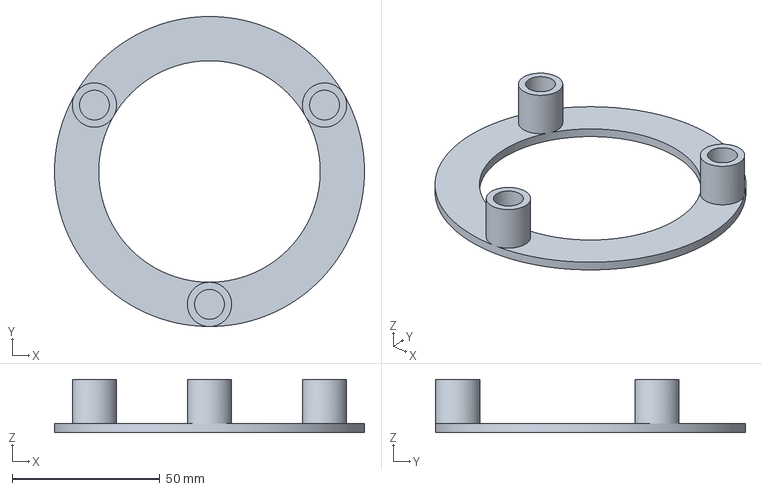
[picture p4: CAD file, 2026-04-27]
KORN_Rev4/cad/DN110_Gegenhalter-Body.amf
105.0 x 105.0 x 18.0 mm

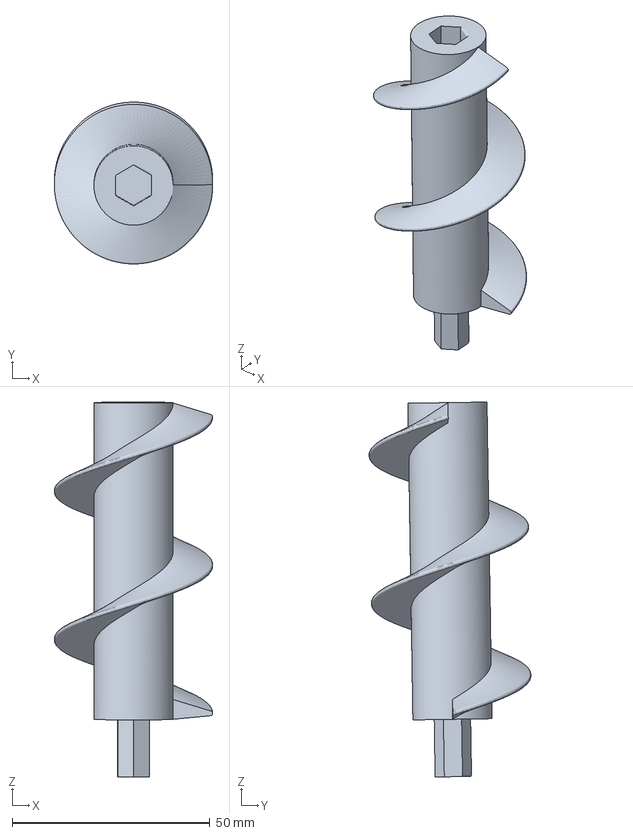
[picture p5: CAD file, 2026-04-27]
KORN_Rev4/cad/Wendel_4.0_steckbar_D-41_DN50-BodyFillet001.3mf
40.0 x 40.9 x 94.7 mm

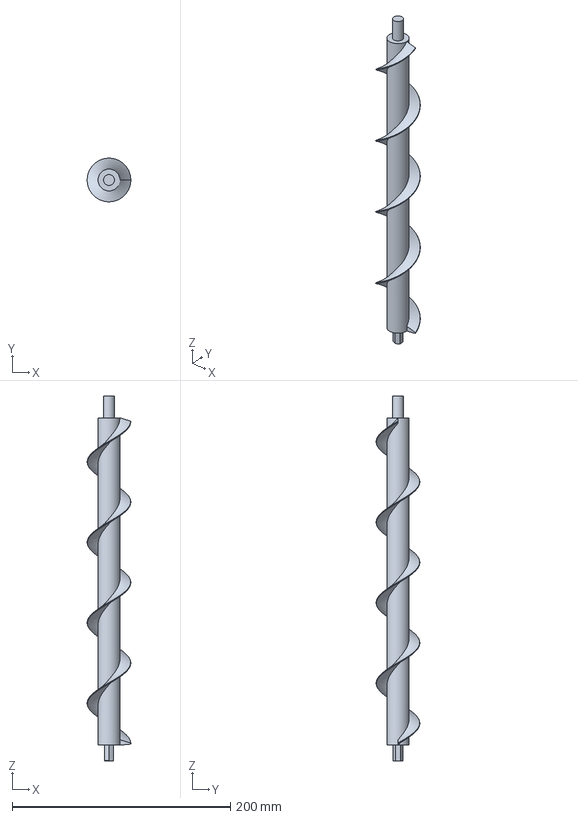
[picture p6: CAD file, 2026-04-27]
KORN_Rev4/cad/Wendel_4.0_steckbar_D-41_L=200_DN50-Body.amf
40.0 x 40.0 x 334.5 mm

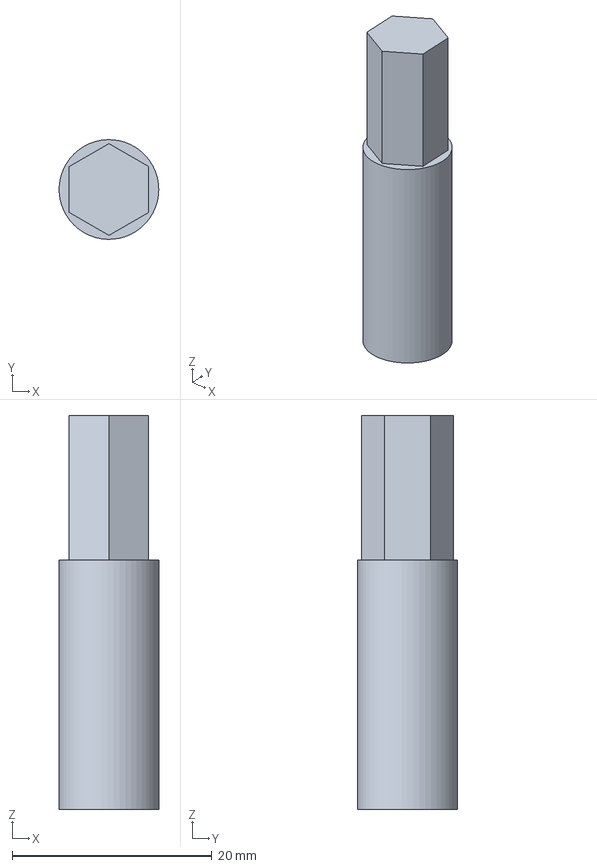
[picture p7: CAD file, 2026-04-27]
KORN_Rev4/cad/Achse-Achsträger.FCStd
9.99 x 10.00 x 39.5 mm

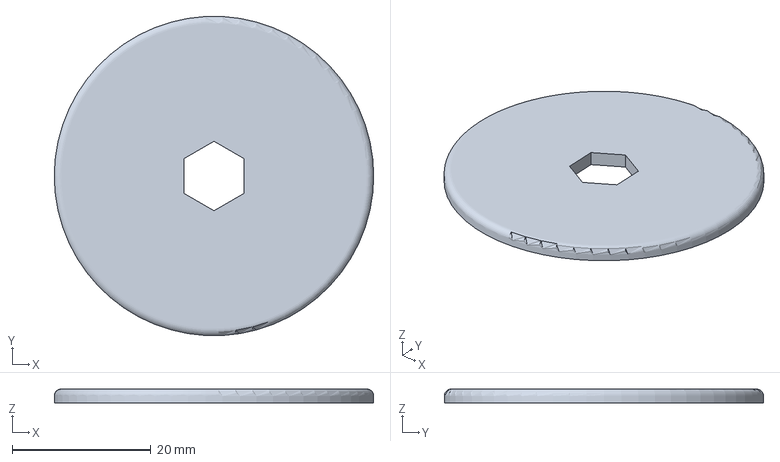
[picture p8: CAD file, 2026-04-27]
KORN_Rev4/cad/Dichtring_DN50-Body.amf
46.0 x 45.9 x 2.00 mm

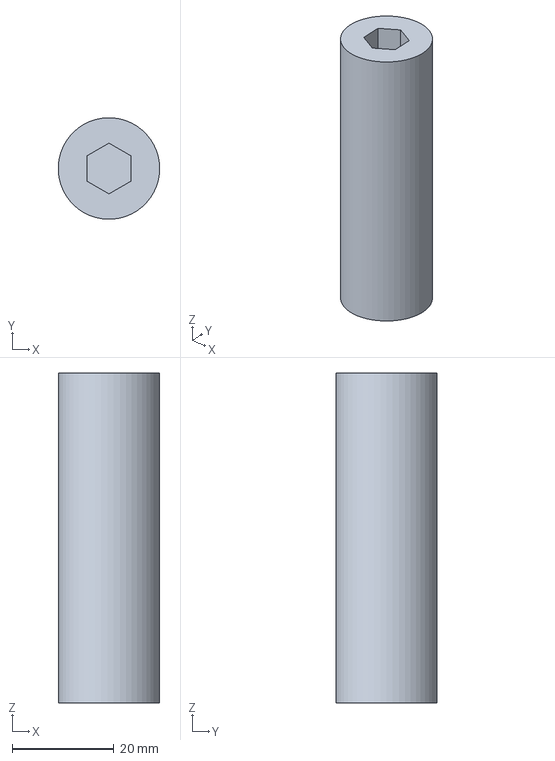
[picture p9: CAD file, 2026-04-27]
KORN_Rev4/cad/DN50_Achse_NEMA17-Wendel.FCStd
20.0 x 20.0 x 65.0 mm

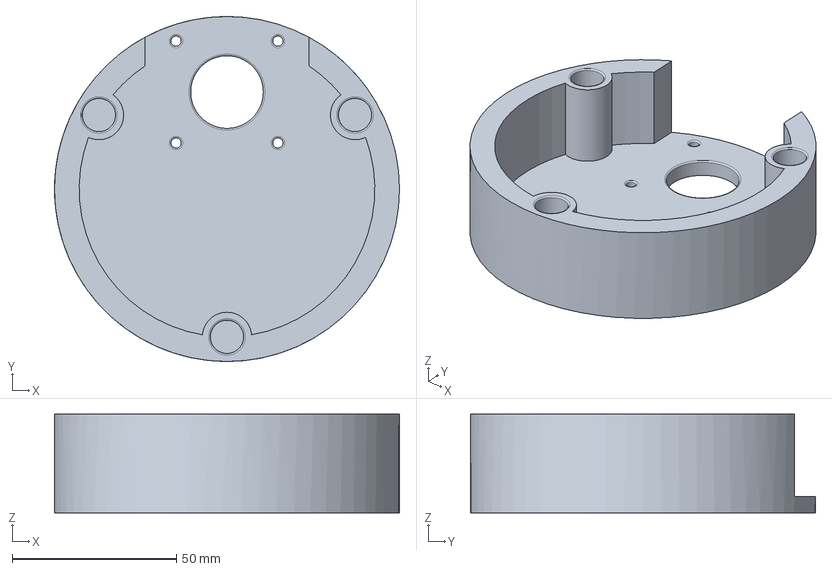
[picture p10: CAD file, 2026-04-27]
KORN_Rev4/cad/DN110_Motorträger.FCStd
105.0 x 105.0 x 30.0 mm

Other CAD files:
KORN_Rev4/cad/Test_KORN_REV4_Assembly.FCStd
KORN_Rev4/cad/KORN_REV4_Assembly4.FCStd
KORN_Rev4/cad/KORN_REV4_Assembly.FCStd
KORN_Rev4/cad/DN50_Achsträger_Rev4-Body.amf
KORN_Rev4/cad/Arduino_Traeger-Body.amf
KORN_Rev4/cad/DN50_Achse_NEMA17-Wendel-Body.amf
KORN_Rev4/cad/Dichtring_DN50.FCStd
KORN_Rev4/cad/Wendel_4.0_steckbar_D-41_L=200_DN50.FCStd
KORN_Rev2/cad/Achse_NEMA17-Wendel.FCStd
KORN_Rev2/cad/Achsträger_DN50.FCStd
KORN_Rev2/cad/Motorträger_Ausgeklinkt Rev.0.1_DN110.FCStd
KORN_Rev2/cad/Motorträger_Ausgeklinkt Rev.0.1_DN90.FCStd
KORN_Rev2/cad/Wendel_2.0_steckbar_D-41_DN50.FCStd
KORN_Rev3/cad/Abstandshalter_Motorträger_DN90.FCStd
KORN_Rev3/cad/Achse-Wendel_auf_Achsträger.FCStd
KORN_Rev3/cad/Achse_NEMA17-Wendel.FCStd
KORN_Rev3/cad/Achsträger_DN50.FCStd
KORN_Rev3/cad/DN110_Motorträger.FCStd
KORN_Rev3/cad/DN110_Motorträger_Achse_RohrtraegerDN50.FCStd
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

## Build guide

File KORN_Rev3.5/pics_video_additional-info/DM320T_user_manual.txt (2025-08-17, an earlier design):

                  User Manual
                          For
                DM320T
          2-Phase Digital Stepper Drive
Address: 15-4, #799 Hushan Road, Jiangning, Nanjing, China
                  Tel: 0086-2587156578
            Web: www.omc-stepperonline.com
             Sales: sales@stepperonline.com
          Support: technical@stepperonline.com
                                                                                                                                          Digital Stepper Driver DM320T
                                                           Table of Contents
1. Introductions.................................................................................................................................................................... 1
     1.1 Features.................................................................................................................................................................. 1
     1.2 Applications............................................................................................................................................................ 1
2. Specifications....................................................................................................................................................................1
     2.1 Electrical Specifications.......................................................................................................................................... 1
     2.2 Environment..........................................................................................................................................................2
     2.3 Mechanical Specifications...................................................................................................................................... 2
     2.4 Elimination of Heat................................................................................................................................................. 2
3. Connection Pin Assignments and LED Indication........................................................................................................... 3
     3.1 Connector P1 Configurations.................................................................................................................................3
     3.2 Connector P2 Configurations.................................................................................................................................3
     3.3 LED Light Indication................................................................................................................................................ 4
4. Control Signal Connector (P1) Interface..........................................................................................................................4
5. Motor Connection............................................................................................................................................................ 5
     5.1 Connections of 4-lead Motor................................................................................................................................. 5
     5.2 Connections of 6-lead Motor................................................................................................................................. 5
          5.2.1 Half Coil Configuration...............................................................................................................................5
          5.2.2 Full Coil Configuration................................................................................................................................ 5
     5.3 Connections of 8-lead Motor................................................................................................................................. 6
          5.3.1 Series Connection....................................................................................................................................... 6
          5.3.2 Parallel Connection..................................................................................................................................... 6
6. Power Supply Selection................................................................................................................................................... 7
     6.1 Regulated or Unregulated Power Supply............................................................................................................... 7
     6.2 Power Supply Sharing............................................................................................................................................. 7
     6.3 Selecting Supply Voltage........................................................................................................................................7
7. DIP Switch Configurations................................................................................................................................................7
     7.1 Microstep Resolution Configurations..................................................................................................................... 8
     7.2 Current Configurations........................................................................................................................................... 8
          7.2.1 Dynamic Current Configurations................................................................................................................8
          7.2.2 Standstill Current Configuration................................................................................................................ 8
     7.3 Automatic Motor Matching & Self Configuration.................................................................................................. 9
8. Wiring Notes....................................................................................................................................................................9
9. Typical Connection..........................................................................................................................................................9
10. Sequence Chart of Control Signals.............................................................................................................................. 10
11. Protection Functions.................................................................................................................................................... 10
12. Troubleshooting........................................................................................................................................................... 11
                                                                                               Digital Stepper Driver DM320T
1. Introductions
The DM320T is a digital stepper drive with simple design and easy setup. By implementing advanced stepper control
technology, this stepper drive is able to power 2-phase and 4 phase stepper motors smoothly with optimal torque and
low motor heating & noise. Its operating voltage is 10-30VDC and it can output up to 2.2A current. All the micro step
and output current are done via DIP switches. Therefore, the DM320T are ideal choices for applications requiring
simple step & direction control of NEMA11, 14, 16, 17 stepper motors.
  1.1 Features
     Anti-Resonance for optimal torque, extra smooth motion, low motor heating and noise
     Motor auto-identification and parameter auto-configuration for optimal torque from wide-range motors
     Step & direction (PUL/DIR) control
     Multi-Stepping for smooth motor movement
     Optically isolated inputs
     Input voltage 10-30VDC
     8 selectable micro-step resolutions of 400-12800 via DIP switches
     8 selectable output current settings of 0.3 – 2.2A via DIP switches
     Soft-start with no “jump” when powered on
     Pulse input frequency up to 60 KHz.
     Automatic idle-current reduction
     Protections for over-voltage and over-current
1.2 Applications
The DM320T stepper drive are designed to power 2 phase (1.8) or 4-phase(0.9) NEMA11, 14, 16, 17 hybrid stepper
motors. It can be easily adopted in many industries (CNC, medical, automation, packaging...), such as X-Y tables,
engraving machines, labeling machines, mills, plasma, laser cutters, pick and place devices, and so on. Its excellent
performance, simple design, and easy setup make it ideal for many step & direction control type applications.
2. Specifications
  2.1 Electrical Specifications
                                                                           DM320T
             Parameters
                                             Min                   Typical                Max                      Unit
           Output Current                    0.3                      -              2.2 (1.6 RMS)                  A
           Supply Voltage                     10                     24                    30                      VDC
         Logic signal current                  7                     10                    16                      mA
        Pulse input frequency                  0                      -                    60                      kHz
         Minimal pulse width                  7.5                     -                     -                       μS
      Minimal direction setup                 7.5                     -                     -                       μS
         Isolation resistance                100                                                                   MΩ
                                                              1
                                                                                           Digital Stepper Driver DM320T
2.2 Environment
             Cooling                                     Natural Cooling or Forced cooling
                                        Environment                      Avoid dust, oil fog and corrosive gases
                                    Ambient Temperature                       0°C - 65°C (32°F - 149°F)
   Operating Environment                  Humidity                                 40%RH－90%RH
                                    Operating Temperature                     0°C - 50°C (32°F - 122°F)
                                          Vibration                               10-50Hz / 0.15mm
     Storage Temperature                                    -20°C - 65°C (-4°F - 149°F)
             Weight                                            Approx. 90g (3.5 oz)
2.3 Mechanical Specifications
(unit: mm [1inch=25.4mm])
                                        Figure 1: Mechanical specifications
                             * Side mounting recommended for better heat dissipation
2.4 Elimination of Heat
    DM320T reliable working temperature should be < 60℃ (140°F)
    It is recommended to mount the drive vertically to maximize heat sink area. Use forced cooling method to cool if
     necessary.
                                                          2
                                                                                                  Digital Stepper Driver DM320T
3. Connection Pin Assignments and LED Indication
The DM320T has two connector blocks P1&P2 (see above picture). P1 is for control signals connections, and P2 is for
power and motor connections. The following tables are brief descriptions of the two connectors. More detailed
descriptions of the pins and related issues are presented in section 4, 5, 9.
3.1 Connector P1 Configurations
       Pin Function                                                        Details
                            Pulse signal: Pulse active at rising edge; 4-5V when PUL-HIGH, 0-0.5V when PUL-LOW.
            PUL             Minimal pulse width of 7.5μs. Add a resistor for current-limiting at +12V or +24V input logic
                            voltage (1K for +12V, 2k for +24V). The same as DIR and ENA signals.
                            DIR signal: This signal has low/high voltage levels to represent two directions of motor
            DIR             rotation.. Minimal direction setup time of 5μs. Also swapping the connection of two wires
                            of a coil (e.g. A+ and A-) to the drive will reverse motor direction.
                            Opto-coupler power supply, and the typical voltage is +5V. Series connect resistors (at the
           OPTO
                            PUL, DIR, ENA terminals) for current-limiting when +12V or +24V used.
                            Enable signal: This signal is used for enabling/disabling the drive. High level +5V (NPN
                            control signal) for enabling the drive and low level for disabling the drive. NPN and
            ENA
                            Differential control signals are on the contrary, namely Low level for enabling.
                            By default it is left UNCONNECTED (ENABLED).
   !
  Notice
           Notes: (1) shielding control signal wires is suggested;
                  (2) To avoid interference, don’t tie PUL/DIR control signal and motor wires together
3.2 Connector P2 Configurations
       Pin Function                                                        Details
           GND             Power supply ground connection.
           +Vdc            Power supply positive connection. Suggest 24VDC power supply voltage
          A+, A-           Motor Phase A connections. Connect motor A+ wire to A+ Pin; motor A- wire to A-
           B+, B-          Motor Phase B connections. Connect motor B+ wire to B+ Pin; motor B- wire to B-
                                                                 3
                                                                                           Digital Stepper Driver DM320T
    !
  Warning
          Warning: Don’t plug or unplug the P1 & P2 terminal block to avoid drive damage or injury when DM320T
                    is powered on.
3.3 LED Light Indication
There are two LED lights for DM320T. The GREEN one is the power indicator which will be always on generally. The
RED one is a protection indicator which will flash 1-2 times in a 3-second period, when protection enabled for a
DM320T. Different number of flashes indicates different protection type (read section 11 for detail).
4. Control Signal Connector (P1) Interface
The DM320T can accept differential and single-ended inputs (including open-collector and NPN output). The DM320T
has 3 optically isolated logic inputs which are located on connector P1 to accept line drive control signals. These
inputs are isolated to minimize or eliminate electrical noises coupled with the drive control signals. Recommend using
line drive control signals to increase noise immunity for the drive in interference environments. In the following
figures, connections to open-collector and NPN signals are illustrated.
                             Figure 2: Connections to open-collector signal (common-anode)
                                    Figure 3: Connections to difference control signal
                                                            4
                                                                                               Digital Stepper Driver DM320T
5. Motor Connection
The DM320T can drive 2-phase and 4-pahse bipolar hybrid stepper motors with 4, 6, or 8 wires.
5.1 Connections of 4-lead Motor
The 4 lead motors are the least flexible and easy to connect. And the Speed – torque of motor depends on winding
inductance. The output current from drive that is multiply the specified phase current by 1.4 to determine the peak
output current.
                                            Figure 4: 4-lead Motor Connections
5.2 Connections of 6-lead Motor
Like 8 lead stepping motors, 6 lead motors have two configurations available for high speed or high torque operations.
The higher speed configuration, or half coil, is described, because it uses one half of the motor’s inductor windings.
The higher torque configuration, or full coil, uses the full coil windings.
5.2.1 Half Coil Configuration
As previously stated, the half coil configuration uses 50% of the motor phase windings. This gives lower inductance,
hence, lower torque output. Like the parallel connection of 8 lead motor, the torque output will be more stable at
higher speeds. This configuration is also referred to as half chopper. In setting the drive output current multiply the
specified per phase (or unipolar) current rating by 1.4 to determine the peak output current.
                               Figure 5: 6-lead motor half coil (higher speed) connections
5.2.2 Full Coil Configuration
The full coil configuration on a six lead motor should be used in applications where higher torque at lower speed is
desired. This configuration is also referred to as full copper. In full coil mode, the motors should be run at only 70% of
their rated current to prevent overheating.
                                                               5
                                                                                             Digital Stepper Driver DM320T
                                Figure 6: 6-lead motor full coil (higher torque) connections
5.3 Connections of 8-lead Motor
8 lead motors offer a high degree of flexibility to the system designer in that they may be connected in series or
parallel, thus satisfying a wide range of applications.
5.3.1 Series Connection
A series motor configuration would typically be used in applications where a higher torque at lower speed is required.
Because this configuration has the most inductance, the performance will start to degrade at higher speed. In series
mode, the motors should also be run at only 70% of their rated current to prevent overheating.
                                         Figure 7: 8-lead motor series connections
5.3.2 Parallel Connection
An 8 lead motor in a parallel configuration offers a more stable, but lower torque at lower speeds. But because of the
lower inductance, there will be higher torque at higher speeds. Multiply the phase (or unipolar) current rating by 1.96,
or the bipolar current rating by 1.4, to determine the peak output current.
                                        Figure 8: 8-lead motor parallel connections
                                                              6
                                                                                            Digital Stepper Driver DM320T
6. Power Supply Selection
The DM320T can power medium and small size stepping motors (frame size from NEMA11 to 17). To get good driving
performances, it is important to select supply voltage and output current properly. Generally speaking, supply voltage
determines the high speed performance of the motor, while output current determines the output torque of the
driven motor (particularly at lower speed). Higher supply voltage will allow higher motor speed to be achieved, at the
price of more noise and heating. If the motion speed requirement is low, it’s better to use lower supply voltage to
decrease noise, heating and improve reliability.
6.1 Regulated or Unregulated Power Supply
Both regulated and unregulated power supplies can be used to supply the drive. However, unregulated power
supplies are preferred due to their ability to withstand current surge and fast response for current change. If you
prefer to a regulated power supply, it is suggested to choose such a power supply specially designed for stepper/servo
controls Or, in the case when only normal switching power supplies are available, it is important to use “OVERSIZE”
high current output rating power supplies (for example, using a 4A power supply for 3A stepper motor) to avoid
problems such as current clamp. On the other hand, if unregulated supply is used, one may use a power supply of
lower current rating than that of motor (typically 50% ～ 70% of motor current). The reason is that the drive draws
current from the power supply capacitor of the unregulated supply only during the ON duration of the PWM cycle,
but not during the OFF duration. Therefore, the average current withdrawn from power supply is considerably less
than motor current. For example, two 3A motors can be well supplied by one power supply of 4A rating.
6.2 Power Supply Sharing
Multiple DM320T drives can share one power supply to reduce cost, if that power supply has enough power capacity.
To avoid cross interference, connect each stepper drive directly to the shared power supply separately. To avoid cross
interference, DO NOT daisy-chain connect the power supply input pins of the Drivers. Instead connect them to power
supply separately.
6.3 Selecting Supply Voltage
The DM320T is designed to operate within 10-30VDC voltage input. When selecting a power supply, besides voltage
from the power supply power line voltage fluctuation and back EMF voltage generated during motor deceleration
needs also to be taken into account. Ideally it is suggested to use a power supply with the output voltage of 24VDC,
leaving room for power line voltage fluctuation and back-EMF.
Higher supply voltage can increase motor torque at higher speeds, thus helpful for avoiding losing steps. However,
higher voltage may cause bigger motor vibration at lower speed, and it may also cause over-voltage protection or
even drive damage. Therefore, it is suggested to choose only sufficiently high supply voltage for intended applications.
7. DIP Switch Configurations
This drive uses an 6-bit DIP switch to set microstep resolution, and motor operating current, as shown below:
                                                             7
                                                                                             Digital Stepper Driver DM320T
7.1 Microstep Resolution Configurations
Microstep resolution is set by SW4, 5, 6 of the DIP switches as shown in the following table:
          Microstep               Steps/rev.(for 1.8°motor)           SW4                 SW5                   SW6
               2                              400                      ON                  ON                    ON
               4                              800                     OFF                  ON                    ON
               8                             1600                      ON                 OFF                    ON
              16                             3200                     OFF                 OFF                    ON
              32                             6400                      ON                  ON                   OFF
              64                            12800                     OFF                  ON                   OFF
              20                             4000                      ON                 OFF                   OFF
              40                             8000                     OFF                 OFF                   OFF
7.2 Current Configurations
For a given motor, higher drive current will make the motor to output more torque, but at the same time causes more
heating in the motor and drive. Therefore, output current is generally set to be such that the motor will not overheat
for long time operation. Since parallel and serial connections of motor coils will significantly change resulting
inductance and resistance, it is therefore important to set drive output current depending on motor phase current,
motor leads and connection methods. Phase current rating supplied by motor manufacturer is important in selecting
drive current, however the selection also depends on leads and connections.
The first three bits (SW1, 2, 3) of the DIP switch are used to set the dynamic current. Select a setting closest to your
motor’s required current.
7.2.1 Dynamic Current Configurations
        Peak Current                    RMS Current                   SW1                 SW2                   SW3
             0.3A                           0.21A                      ON                  ON                    ON
             0.5A                           0.35A                     OFF                  ON                    ON
             0.7A                           0.49A                      ON                 OFF                    ON
             1.0A                           0.71A                     OFF                 OFF                    ON
             1.3A                           0.92A                      ON                  ON                    OFF
             1.6A                           1.13A                     OFF                  ON                    OFF
             1.9A                           1.34A                      ON                 OFF                    OFF
             2.2A                           1.56A                     OFF                 OFF                    OFF
Notes: Due to motor inductance, the actual current in the coil may be smaller than the dynamic current setting,
particularly under high speed condition.
7.2.2 Standstill Current Configuration
The standstill current is set to be 50% of the selected output current. It means standstill current automatically
reduced to 50% of the selected dynamic current 0.4 second after the last pulse.
                                                            8
                                                                                               Digital Stepper Driver DM320T
7.3 Automatic Motor Matching & Self Configuration
When powered on a DM320T will automatically configure itself with the best settings to match the driven stepper
motor for optimal performance. No action is needed.
8. Wiring Notes
    In order to improve anti-interference performance of the drive, it is recommended to use twisted pair shield
     cable.
    To prevent noise incurred in PUL/DIR signal, pulse/direction signal wires and motor wires should not be tied up
     together. It is better to separate them by at least 10 cm, otherwise the disturbing signals generated by motor will
     easily disturb pulse direction signals, causing motor position error, system instability and other failures.
    If only one power supply serves multiple DM320T drives, separately connecting the drives to the power supply is
     recommended instead of daisy-chaining.
 It is prohibited to pull and plug connector P2 while the drive is powered ON, because there is high current
     flowing through motor coils (even when motor is at standstill). Pulling or plugging connector P2 with power on
     will cause extremely high back-EMF voltage surge, which may damage the drive.
9. Typical Connection
A complete stepping system should include stepping motor, stepping drive, power supply and controller (pulse
generator). A typical connection is shown as figure 9.
                                                Figure 9: Typical connection
                                                              9
                                                                                              Digital Stepper Driver DM320T
10. Sequence Chart of Control Signals
In order to avoid some fault operations and deviations, PUL, DIR and ENA should abide by some rules, shown as
following diagram:
                                        Figure 10: Sequence chart of control signals
Remark:
      a)   t1: ENA must be ahead of DIR by at least 5s. Usually, ENA+ and ENA- are NC (not connected). See
           “Connector P1 Configurations” for more information.
      b)   t2: DIR must be ahead of PUL effective edge by 5s to ensure correct direction;
      c)   t3: Pulse width not less than 7.5s;
      d)   t4: Low level width not less than 7.5s.
11. Protection Functions
To improve reliability, the drive incorporates some built-in protections features.
              Time(s) of
  Priority                            Sequence wave of red LED                               Description
                 Blink
                                                                           Over-current protection activated when peak
    1st            1
                                                                           current exceeds the limit.
                                                                           Over-voltage protection activated when drive
    2nd            2
                                                                           working voltage is greater than 34VDC
    3rd            3                                                       Reserved.
When above protections are active, the motor shaft will be free or the red LED blinks. Reset the drive by repowering it
to make it function properly after removing above problems.
                                                             10
                                                                                             Digital Stepper Driver DM320T
12. Troubleshooting
In the event that your drive doesn’t operate properly, the first step is to identify whether the problem is electrical or
mechanical in nature. The next step is to isolate the system component that is causing the problem. As part of this
process you may have to disconnect the individual components that make up your system and verify that they
operate independently. It is important to document each step in the troubleshooting process. You may need this
documentation to refer back to at a later date, and these details will greatly assist our Technical Support staff in
determining the problem should you need assistance.
Many of the problems that affect motion control systems can be traced to electrical noise, controller software errors,
or mistake in wiring.
Problem Symptoms and Possible Causes
                    Symptoms                                                 Possible Problems
                                                    No power
                                                    Microstep resolution setting is wrong
              Motor is not rotating                 DIP switch current setting is wrong
                                                    Fault condition exists
                                                    The drive is disabled
      Motor rotates in the wrong direction          Motor phases may be connected in reverse
                                                    DIP switch current setting is wrong
                 The drive in fault
                                                    Something wrong with motor coil
                                                    Control signal is too weak
                                                    Control signal is interfered
              Erratic motor motion                  Wrong motor connection
                                                    Something wrong with motor coil
                                                    Current setting is too small, losing steps
                                                    Current setting is too small
                                                    Motor is undersized for the application
         Motor stalls during acceleration
                                                    Acceleration is set too high
                                                    Power supply voltage too low
                                                    Inadequate heat sinking / cooling
        Excessive motor and drive heating           Automatic current reduction function not being utilized
                                                    Current is set too high
                                                          11

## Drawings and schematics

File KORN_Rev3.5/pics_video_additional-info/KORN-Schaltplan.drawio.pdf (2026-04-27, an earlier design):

## K.O.R.N. Rev 3.5

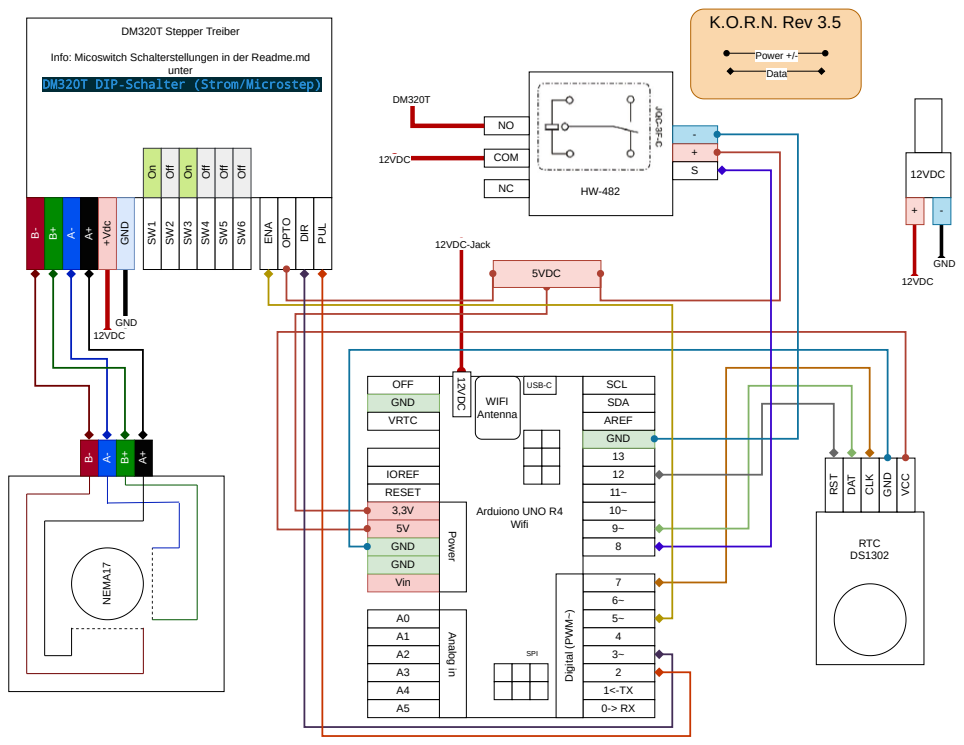
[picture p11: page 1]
OFF; GND; SCL; AREF; SDA; VRTC; IOREF; RESET; Vin; 12VDC-Jack 12VDC; USB-C; SPI; WIFI Antenna; Analog in; Digital (PWM~); Power; Arduiono UNO R4 Wifi; GNDGND; 12VDC⁺Vdc; ENA; OPT; DIR; PUL; DM320T Stepper Treiber; unter; DM320T DIP‑Schalter (Strom/Microstep) On Off; On Off; Off; 12VDC; COM; NEMA17; RTC DS1302; RST; DAT; CLK; VCC; 5VDC; Power +/-; Data

Info: Micoswitch Schalterstellungen in der Readme.md

# Verkabelung 12VDC

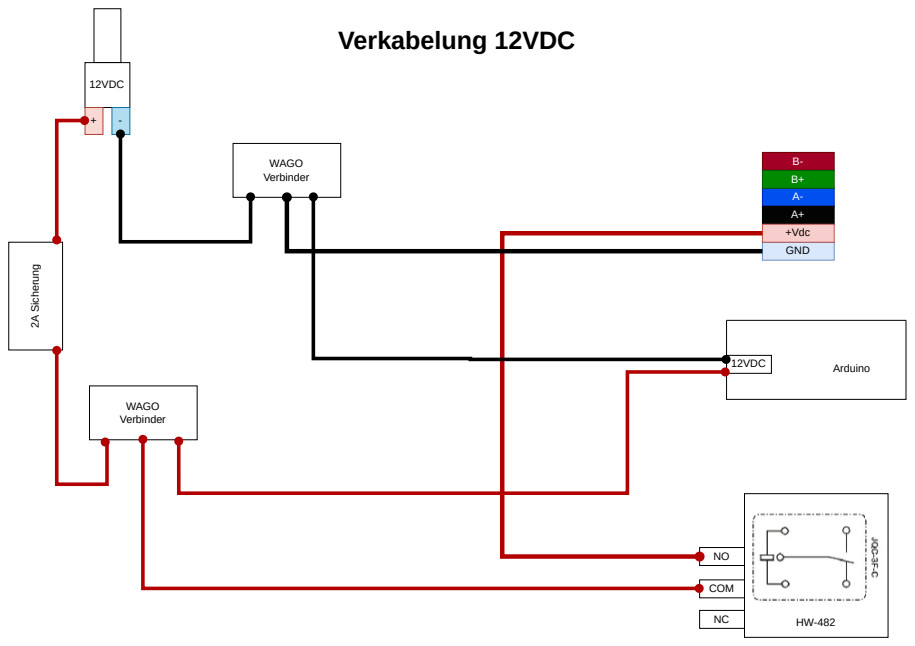
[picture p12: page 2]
12VDC; COM; GND; +Vdc; Arduino; 2A Sicherung; WAGO Verbinder

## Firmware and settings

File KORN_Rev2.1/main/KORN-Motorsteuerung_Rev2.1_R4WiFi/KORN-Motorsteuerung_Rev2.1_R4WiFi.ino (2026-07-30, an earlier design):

/*
 * K.O.R.N. - Katastrophal Organisierter Nahrungsmittel Spender
 * Arduino UNO R4 WiFi - Code mit DS3231 Echtzeituhr für eine präzise tägliche Fütterungszeit
 * 
 * VERDRAHTUNG DS3231:
 * DS3231 VCC  → Arduino 3.3V (oder 5V)
 * DS3231 GND  → Arduino GND
 * DS3231 SDA  → Arduino A4 (SDA)
 * DS3231 SCL  → Arduino A5 (SCL)
 * DS3231 SQW  → NICHT anschließen! 
 * 
 * VERDRAHTUNG MOTORTREIBER:
 * Treiber PUL+ → Arduino Pin 2 (Schrittimpulse)
 * Treiber DIR+ → Arduino Pin 3 (Drehrichtung)
 * Treiber ENA+ → Arduino Pin 5 (Motor aktivieren)
 * Relais IN   → Arduino Pin 8 (Stromversorgung Treiber)
 * 
 * SERIELLER MONITOR: 9600 Baud
 */

#include <AccelStepper.h>
#include <RTClib.h>
#include <Wire.h>
#include <EEPROM.h>   // EEPROM für Arduino UNO R4 WiFi (flash-emuliert, 256 Bytes)

// ============================================================================
// KONFIGURATION - HIER ALLE PARAMETER EINSTELLEN
// ============================================================================

// FÜTTERUNGSZEIT (24h Format)
const int FUETTERUNG_STUNDE_1 = 7;    // Fütterung: 07:01 Uhr. ACHTUNG: Keine führende Null (z.B. 09) - C++ wertet das als Oktalzahl!
const int FUETTERUNG_MINUTE_1 = 1;

// MOTORPARAMETER
const int MOTOR_BESCHLEUNIGUNG = 1000; // Beschleunigung in Steps/s²
// Zeitbasierte Dosierung: feste Schrittfrequenz + Dauer in Sekunden
const int SCHRITTFREQUENZ = 1000;      // Steps pro Sekunde (fix)
const int FUETTERUNG_DAUER_SEK = 3;    // Fütterungsdauer in Sekunden (1–60 s)
const bool MOTOR_RECHTS = false;        // true = Rechts (CW), false = Links (CCW)

// TIMING-PARAMETER
const int RELAIS_VERZOEGERUNG = 2000;  // Verzögerung zwischen Relais-Ein und Motor-Start (ms)
const int MOTOR_PAUSE = 5000;          // Pause nach Motorlauf bevor Relais ausschaltet (ms)
const int LOOP_INTERVALL = 10;         // Pause zwischen zwei Loop-Durchläufen in Sekunden
const int ZEIT_AUSGABE_INTERVALL = 10; // Statusausgabe alle 10 Sekunden
const int FUETTERUNGS_FENSTER_MIN = 2; // Bis Zielzeit +2 Min: Logtext 'Fütterung', danach 'Nachholen' (nur Anzeige, keine Logik)
const int NACHHOLFENSTER_MIN = 60;    // Nachholfenster: Zielzeit bis +60 Minuten

// AUTOMATISCHE ZEITSYNCHRONISATION
const bool ZEIT_EINSTELLEN = false;    // Nur setzen, wenn lostPower() oder explizit gewünscht

// ============================================================================
// PIN-DEFINITIONEN
// ============================================================================
#define PUL_PIN 2    // Schrittimpulse zum Motortreiber
#define DIR_PIN 3    // Drehrichtung zum Motortreiber  
#define OPTO_PIN 4   // Optokoppler (Reserve)
#define ENA_PIN 5    // Motor aktivieren/deaktivieren
#define RELAY_PIN 8  // Relais für Motortreiber-Stromversorgung

// JUMPER-RESET: Pin 12 und 13 verbinden -> EEPROM-Fütterungsdatum löschen
#define JUMPER_PIN_A 12  // Eingang mit internem Pullup
#define JUMPER_PIN_B 13  // GND-Seite (auf OUTPUT LOW)

// ============================================================================
// OBJEKTE UND VARIABLEN
// ============================================================================
AccelStepper stepper(AccelStepper::DRIVER, PUL_PIN, DIR_PIN);
RTC_DS3231 rtc;

// Zustandsvariable für serielle Statusausgabe
unsigned long letzte_ausgabe_ms = 0;  // millis() der letzten seriellen Zeitausgabe (nicht-blockierend)
unsigned long jumperGedruecktMs = 0;  // millis() zu dem Jumper erstmals erkannt wurde

// ============================================================================
// EEPROM - LETZTE FÜTTERUNGSZEIT
// ============================================================================
// Der UNO R4 WiFi nutzt ein flash-emuliertes EEPROM (Data Flash).
// Hier speichern wir das Datum der letzten Fütterung persistent.
const int EEPROM_ADRESSE = 0;

struct LetzteFuetterung {
  uint16_t jahr;
  uint8_t monat;
  uint8_t tag;
  uint8_t stunde;
  uint8_t minute;
};

// Vorwärtsdeklarationen der EEPROM-/Statusfunktionen
void letzte_fuetterung_speichern(DateTime dt);
bool letzte_fuetterung_laden(DateTime &dt, DateTime jetzt);
bool fuetterung_ab_datum(DateTime zielDatum, DateTime letzte);
void zeige_datum(DateTime dt);
void zeige_uhrzeit(DateTime dt);
void zeige_fuetterungsstatus(DateTime jetzt);

// ============================================================================
// JUMPER-RESET: Pin 12 und 13 verbinden -> EEPROM-Fütterungsdatum löschen
// ============================================================================
// sofort=true: löscht sofort beim Start (nur in setup)
// sofort=false: löscht erst nach 3 Sekunden Dauer-Kontakt (im laufenden Betrieb)
// Pin-Konfiguration erfolgt einmalig in setup()
void checkJumperReset(bool sofort) {
  if (digitalRead(JUMPER_PIN_A) == LOW) {
    if (jumperGedruecktMs == 0) jumperGedruecktMs = millis();
    if (sofort || (millis() - jumperGedruecktMs >= 3000UL)) {
      Serial.println("🔌 Jumper Pin 12↔13 erkannt - Fütterungsdatum wird gelöscht...");
      for (int i = 0; i < (int)sizeof(LetzteFuetterung); i++) {
        EEPROM.write(EEPROM_ADRESSE + i, 0xFF);
      }
      Serial.println("✅ EEPROM gelöscht. Jumper entfernen, um fortzufahren...");
      while (digitalRead(JUMPER_PIN_A) == LOW) {
        delay(100);
      }
      Serial.println("🔌 Jumper entfernt - normaler Start.");
      jumperGedruecktMs = 0;
    }
  } else {
    jumperGedruecktMs = 0;
  }
}

void setup() {
  // Pins früh konfigurieren, bevor Ausgänge erstmals genutzt werden
  pinMode(ENA_PIN, OUTPUT);
  pinMode(RELAY_PIN, OUTPUT);
  // Anfangszustand der Ausgänge
  digitalWrite(ENA_PIN, LOW);
  digitalWrite(RELAY_PIN, LOW);

  Serial.begin(9600);              // Serieller Monitor: 9600 Baud
  Serial.println("===========================================");
  Serial.println("🐓 K.O.R.N. Fütterungsautomat gestartet!");
  Serial.println("===========================================");

  // Jumper-Pins einmalig konfigurieren (Pin 12 = Eingang, Pin 13 = GND-Seite)
  pinMode(JUMPER_PIN_B, OUTPUT);
  digitalWrite(JUMPER_PIN_B, LOW);
  pinMode(JUMPER_PIN_A, INPUT_PULLUP);
  delay(10);   // Pullup einschwingen lassen, sonst droht ein Fehl-LOW beim ersten Lesen

  // Jumper-Check: Pin 12 ↔ 13 verbunden = EEPROM-Fütterungsdatum löschen
  checkJumperReset(true);
  
  // I2C starten und RTC initialisieren
  Wire.begin();
#if defined(WIRE_HAS_TIMEOUT)
  Wire.setWireTimeout(3000, true); // 3s Timeout, bei Fehlern Wire zurücksetzen
#endif
  if (!rtc.begin()) {
    Serial.println("FEHLER: DS3231 nicht gefunden!");
    Serial.println("Prüfe Verdrahtung:");
    Serial.println("VCC → 3.3V, GND → GND, SDA → A4, SCL → A5");
    // Dauerhafter Fehler-Alarm: alle 5 Sekunden neuer Verbindungsversuch zur RTC
    while (!rtc.begin()) {
      safeDelay(5000);
    }
    Serial.println("DS3231 wieder gefunden - fahre fort.");
  }
  
  // Zeit und Datum einstellen (automatisch bei Bedarf)
  bool rtc_verlust = false;
  if (rtc.lostPower()) {
    rtc_verlust = true;
    Serial.println("⚠️ RTC verlor Versorgung – Zeit wird neu gesetzt.");
  }
  if (rtc_verlust || ZEIT_EINSTELLEN) {
    rtc.adjust(DateTime(F(__DATE__), F(__TIME__)));
    Serial.println("📡 DS3231 RTC initialisiert / Zeit gesetzt");
  } else {
    Serial.println("⏱️ RTC-Zeit bleibt unverändert (kein Verlust erkannt)");
  }
  // Sanity-Check: Falls RTC-Zeit offensichtlich hinter der Build-Zeit liegt, angleichen
  {
    DateTime build(F(__DATE__), F(__TIME__));
    DateTime nowCheck = rtc.now();
    if (nowCheck.unixtime() + 60 < build.unixtime()) { // >60 s hinter Build-Zeit
      Serial.println("⚠️ RTC-Zeit liegt vor Build-Zeit – setze auf Build-Zeit.");
      rtc.adjust(build);
    }
  }
  
  // Synchronisierte/aktuelle Zeit einmalig anzeigen
  {
    DateTime jetzt = rtc.now();
    Serial.print("📅 Datum: ");
    Serial.print(jetzt.day(), DEC);
    Serial.print(".");
    Serial.print(jetzt.month(), DEC);
    Serial.print(".");
    Serial.print(jetzt.year(), DEC);
    Serial.println();
  }
  
  // Aktuelle Zeit anzeigen
  zeige_aktuelle_zeit(rtc.now());
  
  // Motor konfigurieren (zeitbasierte Dosierung): feste Schrittfrequenz
  stepper.setMaxSpeed(SCHRITTFREQUENZ);
  stepper.setAcceleration(MOTOR_BESCHLEUNIGUNG);
  
  // Pins wurden bereits zu Beginn von setup() konfiguriert und initialisiert
  
  Serial.println("-------------------------------------------");
  Serial.println("Konfigurierte Fütterungszeit:");
  Serial.print("Fütterung: "); 
  formatiere_zeit(FUETTERUNG_STUNDE_1, FUETTERUNG_MINUTE_1);
  Serial.println("-------------------------------------------");
  zeige_fuetterungsstatus(rtc.now());
  Serial.println("System bereit! Loop alle 10 s, Statusausgabe alle 10 s.");
  Serial.println("===========================================");
}

void loop() {
  // Jumper-Reset auch im laufenden Betrieb ermöglichen (mind. 3 s halten)
  checkJumperReset(false);

  DateTime jetzt = rtc.now();

  // Plausibilitätsprüfung: bei I2C-Störung können Müllwerte kommen
  if (jetzt.year() < 2024 || jetzt.year() > 2099 ||
      jetzt.month() < 1 || jetzt.month() > 12 ||
      jetzt.day() < 1 || jetzt.day() > 31 ||
      jetzt.hour() > 23 || jetzt.minute() > 59 || jetzt.second() > 59) {
    Serial.println("⚠️ Ungültige RTC-Zeit gelesen - Durchlauf wird übersprungen!");
    safeDelay(1000);
    return;
  }

  // Statusausgabe alle ZEIT_AUSGABE_INTERVALL Sekunden (nicht-blockierend über millis())
  unsigned long nowMs = millis();
  if (nowMs - letzte_ausgabe_ms >= (unsigned long)ZEIT_AUSGABE_INTERVALL * 1000UL) {
    zeige_aktuelle_zeit(jetzt);
    zeige_fuetterungsstatus(jetzt);
    letzte_ausgabe_ms = nowMs;
  }

  // Letztes Fütterungsdatum aus EEPROM laden
  DateTime letzte;
  bool letzteGueltig = letzte_fuetterung_laden(letzte, jetzt);

  // Fütterungsfenster berechnen (Zielzeit heute und gestern, da das 60-Min-Fenster über Mitternacht greifen kann)
  DateTime zielHeute = DateTime(jetzt.year(), jetzt.month(), jetzt.day(), FUETTERUNG_STUNDE_1, FUETTERUNG_MINUTE_1, 0);
  DateTime zielGestern = zielHeute - TimeSpan(86400L);
  DateTime heuteFensterEnde = zielHeute + TimeSpan((long)NACHHOLFENSTER_MIN * 60L);
  DateTime gesternFensterEnde = zielGestern + TimeSpan((long)NACHHOLFENSTER_MIN * 60L);

  bool imHeutigenFenster = (jetzt >= zielHeute && jetzt <= heuteFensterEnde);
  bool imGestrigenFenster = (jetzt >= zielGestern && jetzt <= gesternFensterEnde);

  // Prüfen, ob für das jeweilige Fenster noch nicht gefüttert wurde
  bool heuteFutterNoetig = imHeutigenFenster && (!letzteGueltig || !fuetterung_ab_datum(zielHeute, letzte));
  bool gesternFutterNoetig = imGestrigenFenster && (!letzteGueltig || !fuetterung_ab_datum(zielGestern, letzte));

  if (heuteFutterNoetig || gesternFutterNoetig) {
    DateTime zielAktuell = heuteFutterNoetig ? zielHeute : zielGestern;
    // Logtext-Unterscheidung anhand der tatsächlichen Erkennungszeit
    TimeSpan seitZiel = jetzt - zielAktuell;

    if (seitZiel.totalseconds() <= (long)FUETTERUNGS_FENSTER_MIN * 60L) {
      Serial.println("🍽️ FÜTTERUNG STARTET...");
    } else {
      Serial.println("🍽️ Fütterung startet (Nachholen)...");
    }

    // Datum sofort speichern, BEVOR der Motor anfährt, um Doppelfütterungen zu vermeiden.
    // Beim Nachholen des gestrigen Fensters (Mitternacht-Übergang) wird der gestrige
    // Zielzeitpunkt gespeichert, damit die heutige Fütterung nicht als erledigt gilt.
    DateTime gespeichert = heuteFutterNoetig ? jetzt : zielGestern;
    letzte_fuetterung_speichern(gespeichert);
    Serial.print("💾 Fütterungsdatum gespeichert: ");
    zeige_datum(gespeichert);
    Serial.print(" ");
    zeige_uhrzeit(gespeichert);
    if (!heuteFutterNoetig) {
      Serial.print(" (nachgeholt am ");
      zeige_datum(jetzt);
      Serial.print(" um ");
      zeige_uhrzeit(jetzt);
      Serial.print(")");
    }
    Serial.println();

    fuetterungsvorgang();
    Serial.println("✅ Fütterung abgeschlossen!");
  }

  // Pause zwischen zwei Loop-Durchläufen, dabei regelmäßig Jumper prüfen
  unsigned long loopStart = millis();
  while (millis() - loopStart < (unsigned long)LOOP_INTERVALL * 1000UL) {
    checkJumperReset(false);
    delay(50);
  }
}

// ============================================================================
// FÜTTERUNGSVORGANG - Motor ansteuern
// ============================================================================
void fuetterungsvorgang() {
  Serial.println("→ Relais aktivieren...");
  digitalWrite(RELAY_PIN, HIGH);           // Motortreiber mit Strom versorgen
  safeDelay(RELAIS_VERZOEGERUNG);          // Warten bis Treiber bereit
  
  Serial.println("→ Motor aktivieren...");
  digitalWrite(ENA_PIN, HIGH);             // Motor aktivieren
  
  // Schritte für diese Fütterung aus Dauer berechnen (1–60 s)
  const int sek = constrain(FUETTERUNG_DAUER_SEK, 1, 60);
  const long schritte = (long)sek * SCHRITTFREQUENZ;
  Serial.print("→ Motor läuft ");
  Serial.print(sek);
  Serial.print(" s = ");
  Serial.print(schritte);
  Serial.println(" Schritte...");
  
  if (MOTOR_RECHTS) {
    stepper.move(schritte);                // relative Bewegung im Uhrzeigersinn
  } else {
    stepper.move(-schritte);               // relative Bewegung gegen Uhrzeigersinn
  }
  // Bewegung ausführen (blockierend)
  while (stepper.distanceToGo() != 0) {
    stepper.run();
  }
  
  Serial.println("→ Motor stoppen...");
  digitalWrite(ENA_PIN, LOW);              // Motor deaktivieren
  
  safeDelay(MOTOR_PAUSE);                  // Kurze Pause
  
  Serial.println("→ Relais deaktivieren...");
  digitalWrite(RELAY_PIN, LOW);            // Motortreiber stromlos schalten
}

// ============================================================================
// HILFSFUNKTIONEN FÜR ZEITAUSGABE
// ============================================================================
void zeige_aktuelle_zeit(DateTime jetzt) {
  Serial.print(" Aktuelle Zeit: ");
  
  // Datum formatieren
  if (jetzt.day() < 10) Serial.print("0");
  Serial.print(jetzt.day());
  Serial.print(".");
  if (jetzt.month() < 10) Serial.print("0");
  Serial.print(jetzt.month());
  Serial.print(".");
  Serial.print(jetzt.year());
  Serial.print(" ");
  
  // Uhrzeit formatieren
  if (jetzt.hour() < 10) Serial.print("0");
  Serial.print(jetzt.hour());
  Serial.print(":");
  if (jetzt.minute() < 10) Serial.print("0");
  Serial.print(jetzt.minute());
  Serial.print(":");
  if (jetzt.second() < 10) Serial.print("0");
  Serial.print(jetzt.second());
  
  // Temperatur vom DS3231 anzeigen (Bonus-Feature)
  Serial.print(" | Temp: ");
  Serial.print(rtc.getTemperature());
  Serial.println("°C");
}

// ============================================================================
// EEPROM: LETZTE FÜTTERUNGSZEIT SPEICHERN/LADEN
// ============================================================================
void letzte_fuetterung_speichern(DateTime dt) {
  LetzteFuetterung lf;
  lf.jahr = dt.year();
  lf.monat = dt.month();
  lf.tag = dt.day();
  lf.stunde = dt.hour();
  lf.minute = dt.minute();
  EEPROM.put(EEPROM_ADRESSE, lf);
}

bool letzte_fuetterung_laden(DateTime &dt, DateTime jetzt) {
  LetzteFuetterung lf;
  EEPROM.get(EEPROM_ADRESSE, lf);

  // Gültigkeitsprüfung (leerer/uninitialisierter EEPROM hat 0xFF = 65535/255)
  if (lf.jahr < 2024 || lf.jahr > 2099) return false;
  if (lf.monat < 1 || lf.monat > 12) return false;
  if (lf.tag < 1 || lf.tag > 31) return false;

  // Abwärtskompatibilität: alter 4-Byte-Eintrag ohne Uhrzeit -> 00:00 annehmen
  if (lf.stunde == 0xFF && lf.minute == 0xFF) {
    lf.stunde = 0;
    lf.minute = 0;
  }

  if (lf.stunde > 23 || lf.minute > 59) return false;

  dt = DateTime(lf.jahr, lf.monat, lf.tag, lf.stunde, lf.minute, 0);

  // Zukunftsdatum ist ungültig (z. B. nach RTC-Reset auf ältere Build-Zeit).
  // Sonst würde bis zum gespeicherten Datum gar nicht mehr gefüttert.
  DateTime heute0(jetzt.year(), jetzt.month(), jetzt.day(), 0, 0, 0);
  if (dt >= heute0 + TimeSpan(86400L)) return false;

  return true;
}

void zeige_datum(DateTime dt) {
  if (dt.day() < 10) Serial.print("0");
  Serial.print(dt.day());
  Serial.print(".");
  if (dt.month() < 10) Serial.print("0");
  Serial.print(dt.month());
  Serial.print(".");
  Serial.print(dt.year());
}

void zeige_uhrzeit(DateTime dt) {
  if (dt.hour() < 10) Serial.print("0");
  Serial.print(dt.hour());
  Serial.print(":");
  if (dt.minute() < 10) Serial.print("0");
  Serial.print(dt.minute());
}

bool fuetterung_ab_datum(DateTime zielDatum, DateTime letzte) {
  // true, wenn die letzte Fütterung am zielDatum oder danach stattfand
  return (letzte.year() > zielDatum.year()) ||
         (letzte.year() == zielDatum.year() && letzte.month() > zielDatum.month()) ||
         (letzte.year() == zielDatum.year() && letzte.month() == zielDatum.month() && letzte.day() >= zielDatum.day());
}

// ============================================================================
// FÜTTERUNGSSTATUS: LETZTE FÜTTERUNG UND ZEIT BIS ZUR NÄCHSTEN
// ============================================================================
void zeige_fuetterungsstatus(DateTime jetzt) {
  Serial.print("🍽️ Letzte Fütterung: ");
  DateTime letzte;
  bool letzteGueltig = letzte_fuetterung_laden(letzte, jetzt);
  if (letzteGueltig) {
    zeige_datum(letzte);
    Serial.print(" ");
    zeige_uhrzeit(letzte);
  } else {
    Serial.print("noch keine");
  }

  Serial.print(" | ⏳ Nächste: ");

  // Zielzeit heute, gestern (Mitternacht-Übergang) und morgen
  DateTime zielHeute = DateTime(jetzt.year(), jetzt.month(), jetzt.day(), FUETTERUNG_STUNDE_1, FUETTERUNG_MINUTE_1, 0);
  DateTime zielGestern = zielHeute - TimeSpan(86400L);
  DateTime zielMorgen = zielHeute + TimeSpan(86400L);
  DateTime heuteFensterEnde = zielHeute + TimeSpan((long)NACHHOLFENSTER_MIN * 60L);
  DateTime gesternFensterEnde = zielGestern + TimeSpan((long)NACHHOLFENSTER_MIN * 60L);

  bool imHeutigenFenster = (jetzt >= zielHeute && jetzt <= heuteFensterEnde);
  bool imGestrigenFenster = (jetzt >= zielGestern && jetzt <= gesternFensterEnde);

  // Heute schon gefüttert? (auch wenn im gestrigen Fenster aufgeholt wurde)
  DateTime heuteDatum(jetzt.year(), jetzt.month(), jetzt.day(), 0, 0, 0);
  bool heuteGefuettert = letzteGueltig && fuetterung_ab_datum(heuteDatum, letzte);

  DateTime naechsteFuetterung;
  if (imHeutigenFenster && (!letzteGueltig || !fuetterung_ab_datum(zielHeute, letzte))) {
    naechsteFuetterung = jetzt;  // innerhalb des heutigen Fensters fällig
  } else if (imGestrigenFenster && (!letzteGueltig || !fuetterung_ab_datum(zielGestern, letzte))) {
    naechsteFuetterung = jetzt;  // innerhalb des gestrigen Nachholfensters fällig
  } else if (heuteGefuettert || jetzt > heuteFensterEnde) {
    naechsteFuetterung = zielMorgen;  // nächste Fütterung morgen
  } else {
    naechsteFuetterung = zielHeute;   // nächste Fütterung heute zum Zielzeitpunkt
  }

  zeige_datum(naechsteFuetterung);
  Serial.print(" ");
  zeige_uhrzeit(naechsteFuetterung);
  Serial.print(" (in ");

  TimeSpan diff = naechsteFuetterung - jetzt;
  long verbleibend = diff.totalseconds();
  if (verbleibend < 0) verbleibend = 0;

  Serial.print(verbleibend / 3600);
  Serial.print("h ");
  Serial.print((verbleibend % 3600) / 60);
  Serial.print("m ");
  Serial.print(verbleibend % 60);
  Serial.println("s)");
}

// ============================================================================
// ZEITHELFER: blockierende Verzögerung in kleinen Schritten
// ============================================================================
void safeDelay(unsigned long ms) {
  unsigned long start = millis();
  while (millis() - start < ms) {
    delay(50);
  }
}

void formatiere_zeit(int stunde, int minute) {
  if (stunde < 10) Serial.print("0");
  Serial.print(stunde);
  Serial.print(":");
  if (minute < 10) Serial.print("0");
  Serial.print(minute);
  Serial.println(" Uhr");
}

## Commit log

2024-09-29 Initial push of K.O.R.N.
    [Achse-Achsträger.FCStd, Achse_NEMA17-Wendel.FCStd, Achsträger.FCStd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]
2025-06-02 Aktualisiert Motorsteuerung mit Buzzer und RTC
    [Achse-Achsträger.FCStd, Achse_NEMA17-Wendel.FCStd, Achsträger.FCStd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]
2025-06-02 Aktualisiert Motorsteuerung mit Buzzer und RTC1.0
2025-06-20 CAD Dateien fuer DN110
    [Achse-Achsträger.FCStd, Achse_NEMA17-Wendel.FCStd, Achsträger.FCStd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]
2025-06-20 Bezeichnung aktualisiert
    [Achse-Wendel_auf_Achsträger.FCStd, DN110_Gegenhalter.FCStd, DN110_Motorträger.FCStd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]
2025-06-21 Wendel aktualisiert
    [DN110_Motorträger.FCStd, DN50_Wendel_2.0_steckbar_D-41.FCStd, Wendel_2.0_steckbar_D-41_DN50.FCStd]
2025-07-09 🚀 Major Arduino optimization & documentation update
    ✅ RAM-Optimierung:
    - F() Makro für alle String-Literale (Flash statt RAM)
    - Serielle Ausgaben drastisch gekürzt (stichpunktartig)
    - Speicher-effiziente Debug-Funktionen
    ✅ Code-Robustheit:
    - Kompilierungsfehler behoben
    - Konsistente Variablennamen
    - Verbesserte RTC-Initialisierung
    - Watchdog-Integration
    ✅ Dokumentation:
    - README komplett erweitert
    - Technische Details und Hardware-Setup
    - Installation & Konfiguration
    - Troubleshooting-Guide
    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
    [KORN_18.08.2024.ino]
2025-08-17 Aktualisiert cad/Motortraeger-Abstandshalter
    [Abstandshalter_Motorträger-Body.3mf, Abstandshalter_Motorträger.FCStd]
2025-08-17 chore(repo): Verzeichnisstruktur neu organisiert
    interaktives Rebase im Gange; auf d5af375
    Letzte Befehle erledigt (2 Befehle erledigt):
    pick 662e9b2 Aktualisiert cad/Motortraeger-Abstandshalter
    pick 624d582 chore(repo): Verzeichnisstruktur neu organisiert
    Keine Befehle verbleibend.
    Sie sind gerade beim Rebase von Branch 'main' auf 'd5af375'.
    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
    [Abstandshalter_Motorträger-Body.3mf, Abstandshalter_Motorträger.FCStd, Abstandshalter_Motorträger_DN90.FCStd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]
2025-08-17 chore(repo): Duplikate entfernt und Dateien umbenannt
    [Verdrahtung_KORN_REV3.fzz]
2025-08-19 KORN Rev3: IP in Status dynamisch (WiFi.localIP); Motor-Flags (ENABLE_ACTIVE_HIGH/INVERT_STEP); STEP-Pulsbreite 8µs; RTC immer auf Uploadzeit; README: DM320T DIP-Varianten & Verkabelung
2025-08-24 Batterie-Heuristik: batteryLikelyOK() + UI-Indikator (Grün/Rot); Web-UI/README zuvor aktualisiert
2025-08-27 Add K.O.R.N. project with Rev2 and Rev3 versions
    - Added KORN_Rev2 with CAD files, motor control code, and documentation
    - Added KORN_Rev3 with updated CAD files, improved motor control script
    - Includes Arduino sketches for motor control, web interface, and AP mode
    - Added project documentation and README
2025-10-30 Rev3: EEPROM-Backup, DS1302 5V Fix, Relay-Polarität, Blockade-Lösen Fix
    [homepage.ino, main.ino, motor.ino]
2025-10-30 Rev3: EEPROM-Backup, DS1302 5V Fix, Relay-Polarität, Stromverbrauch-Update
2025-10-30 Rev3: EEPROM-Backup, DS1302 5V Fix, Relay-Polarität, Stromverbrauch-Update, Bilder
2026-04-27 Rev3.5:CAD-Dateien Wendel geändert, Buzzer Jagdsignal, DHCP-Hostname, Captive Portal, WIFI Integration
    [Achse-Achsträger.FCStd, Arduino_Traeger-Body.amf, Arduino_Traeger.FCStd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]
2026-04-27 Rev3.5 fertiggestellt: DHCP-Hostname, Captive Portal, NTP-Zeit, Jagdsignal, Bugfixes
    [Abstandshalter_Motorträger_DN90.FCStd, Achse-Achsträger.FCStd, Achse-Wendel_auf_Achsträger.FCStd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]
2026-04-27 Rev3.5: kvFind URL-Decoding-Fix, Forward-Decl, gNtpDay-Range, Doku-Politur
    [homepage.ino, main.ino, motor.ino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]
2026-05-15 Rev3.5: Fix NTP-Drift-Bug (Geister-Auslösung), Web-Log /log, Diagnose-Logs; Logfiles ignorieren
    [homepage.ino, main.ino]
2026-05-22 Datum auf Homepage und in Serial/Log anzeigen; ntpGetDateTime nun global
2026-05-22 Interne Projektpläne und Projektbeschreibungen aus Repo entfernen und ignorieren
2026-05-22 Doku: Datumsanzeige und /log Diagnose; Root-Logs entfernen und ignorieren
2026-07-13 Rev2: Code-Review-Fixes (RTC-Alarm, Zeitausgabe, Plausibilitätsprüfung), eine Fütterung pro Tag, README aktualisiert
    [KORN-Motorsteuerung_Rev2.ino]
2026-07-30 Rev2.1: Robustheits-Fixes (Mitternacht-Nachholen, EEPROM-Zukunftsdatum, erweiterte RTC-Plausibilitaet), Jumper-Init in setup, README-Hinweis zu Beispielwerten
    [KORN-Motorsteuerung_Rev2.1_R4WiFi.ino]
2026-10-16 Rev3.1 + Rev3.6 ergänzt, Rev2-Scheduler sekundengenau, .env enttrackt
    - Rev3.1: DS3231 statt DS1302, Config nur EEPROM, Jagdsignal,
    millis()-Fallback bei RTC-Ausfall, bootet ohne USB
    - Rev3.6: NTP-Client mit Notfütterung (8/16h) + Fallback-AP.
    Achtung: wifi_client.ino unvollständig, kompiliert noch nicht
    - Rev2: Crossing-Detektion wie Rev3, nicht-blockierende
    Zeitausgabe, Fütterungszeit 17:25, Dauer 10s
    - Rev3.5: Futterhinweise (Pfau/Deuka) in Web-UI,
    README_REV3.5.md -> README.md
    - Rev3: README_Rev4.md -> README.md, README_Rev3.md ergänzt
    - Root-README: Rev3.1-Abschnitt ergänzt, Rev3.5-Link korrigiert
    - .env aus Tracking entfernt und ignoriert (fremde
    OpenProject-Platzhalter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
2026-10-16 Rev3.1 Stabilitaets-Paket aus Rev2.1, Rev2.1 Fehlerbehandlung, Readmes umbenannt
    Rev3.1 (fuer Off-Grid-Umzug von stabiler 2.1-Basis):
    - Nachhol-Fenster (60 min): verpasste Fuetterung nach Strom-/Solar-Ausfall wird
    wie in Rev2.1 einmalig nachgeholt; Crossing-Detektion bleibt fuer exakte :00
    - FeedState persistent im EEPROM (Magic+CRC, Adresse 32): fedToday1/2,
    lastFeed*, Datum -> keine Doppelfuetterung nach Reboot
    - RTC-Plausibilitaet auf alle Felder erweitert (J/M/T/h/m/s), zentrale Funktion
    - Build-Zeit-Sanity: RTC deutlich hinter Kompilierzeit -> wird korrigiert
    - Wire.setWireTimeout(3s) gegen I2C-Haenger
    - Hardware-Watchdog auf UNO R4 (WDT.h, 4s), aktiviert erst nach apInit(),
    Refre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
2026-10-16 Rev3/Rev3.1: Fake-Batteriestatus durch CR2032-Alters-Tracker ersetzt
    Hintergrund:
    Der bisherige Batterie-Indikator (gruen/rot) mass keine Spannung, sondern
    wertete nur RTC-Heuristiken aus (Rev3.1: lostPower-Flag, Rev3: RTC-RAM-
    Config). Das suggerierte eine Messung, die ohne Zusatzhardware
    (A/D-Eingang) gar nicht moeglich ist - und loeste falsche
    Tausch-Warnungen aus.
    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
2026-10-16 Rev3.1: Doppelfuetterungs-Luecke bei Reboot nach Fuetterung geschlossen
    Problem:
    Der fedToday-Marker wurde erst NACH requestImmediateFeed() im RAM
    gesetzt - der EEPROM-Save innerhalb der Funktion speicherte also noch
    fedToday=false. Ein Reboot (Stromwackler, Watchdog-Reset) innerhalb
    des 60-Minuten-Nachhol-Fensters nach einer planmaessigen Fuetterung
    haette erneut gefuettert.
    Fix (Rev2.1-Prinzip "angefangene Fuetterung zaehlt als erledigt"):
    fedToday1/2 wird jetzt VOR dem Motorstart gesetzt und sofort
    persistiert (feedStateSave). Nebeneffekt gewollt: Bei Motor-Timeout
    wird am selben Tag nicht endlos neu versucht.
    Gefunden beim Review vor einer Woche unbeaufsichtigtem Betrieb.
    Generated wi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
2026-10-16 Rev3/Rev3.1: Vorwaertsdeklaration struct BattInfo (Compile-Fehler)
    Der Arduino-Praeprozessor setzt auto-generierte Funktions-Prototypen
    (battChecksum, battLoad) an den Dateianfang - vor die Definition von
    struct BattInfo. Ohne Vorwaertsdeklaration bricht der Build ab:
    "'BattInfo' does not name a type".
    Gleiche Loesung wie bereits bei KConfig und FeedState.
    In Rev3 vorsorglich mitgefixt (gleicher Code, gleiches Problem).
    Generated with [Devin](https://devin.ai)
2026-10-16 Readmes: TODO-Hinweis RTC-Tausch gegen ZS-042 (DS3231) mit LIR2032
    In readme_rev2, readme_rev2.1, readme_rev3 und readme_rev3.1 ergaenzt:
    - Empfehlung, das RTC-Modul gegen ein ZS-042 mit wiederaufladbarer
    LIR2032 zu tauschen (onboard-Ladeschaltung -> kein periodischer
    Batteriewechsel, kein Ueberlade-Risiko wie bei CR2032)
    - In readme_rev3 zusaetzlich der Hinweis, dass Rev3 eine DS1302
    (3-Draht-RTC, D7/D9/D12) verwendet: das ZS-042 ist DS3231/I2C,
    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
2026-10-16 Rev3.1: fedToday-Marker sichtbar + resettbar, Unterdrueckung geloggt
    Problem: Wurde Fuetterung 2 heute bereits ausgeloest (z. B. zur
    Standardzeit oder per Test), unterdrueckt der EEPROM-persistente
    Tagesmarker alle weiteren Ausloesungen - stillschweigend, auch nach
    Umstellen der Uhrzeit oder Reflash. Beim Anwender sieht das aus wie
    "Scheduler defekt".
    Neu:
    - Statuszeile "Heute gefuettert: 1:ja/nein 2:ja/nein" auf der Homepage
    - Button "Tagesmarker zuruecksetzen (Test)" (POST /feedreset):
    loescht fedToday1/2 + pending-Flags und speichert ins EEPROM.
    Funktionaler Ersatz fuer den EEPROM-Reset-Jumper (12<->13) aus Rev2.1
    - Log-Eintrag "SCHEDx unterdrueckt: heute gefuettert" beim Crossing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
2026-10-16 Rev3.1: Werksreset ersetzt Marker-Reset, Nachhol-Fenster nach Reset gesperrt
    Problem: Der Tagesmarker-Reset loeste sofort eine Fuetterung aus -
    nach dem Leeren der Marker sah das System aus wie nach Stromausfall,
    und das Nachhol-Fenster fuetterte beide verpassten Termine nach
    (erste sofort, zweite 2min spaeter via Pending). Die Anzeige sprang
    dadurch zurueck auf "1:ja 2:ja".
    - Werksreset-Button (POST /factoryreset): setzt das komplette System
    auf Anfang - Config -> Defaults, Fuetterungszustand geloescht,
    Batterie-Einbaudatum geloescht
    - Neues EEPROM-Feld suppressDay im FeedState: sperrt das
    Nachhol-Fenster fuer den Reset-Tag (persistent, ueberlebt Reboots),
    ab Mitternacht autom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
